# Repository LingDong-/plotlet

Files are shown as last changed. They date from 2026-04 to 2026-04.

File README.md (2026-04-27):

# plotlet

A $20 pen-plotter design that you can (almost) entirely 3D-print yourself. Optionally wireless: Bluetooth-operated and battery powered with upgrades.

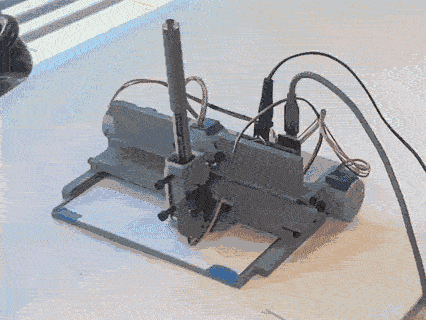
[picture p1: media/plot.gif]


While not as fast or accurate as a full-blown plotter with metal parts and big motors, this delightful little machine is surprisingly capable for a tiny fraction of the cost. The default work area is the size of a postcard (6''x4''), while a simple modification allows it to cover 6''x ∞.

## Gallery

Below are some plots made with the plotter. Click on the image to enlarge.

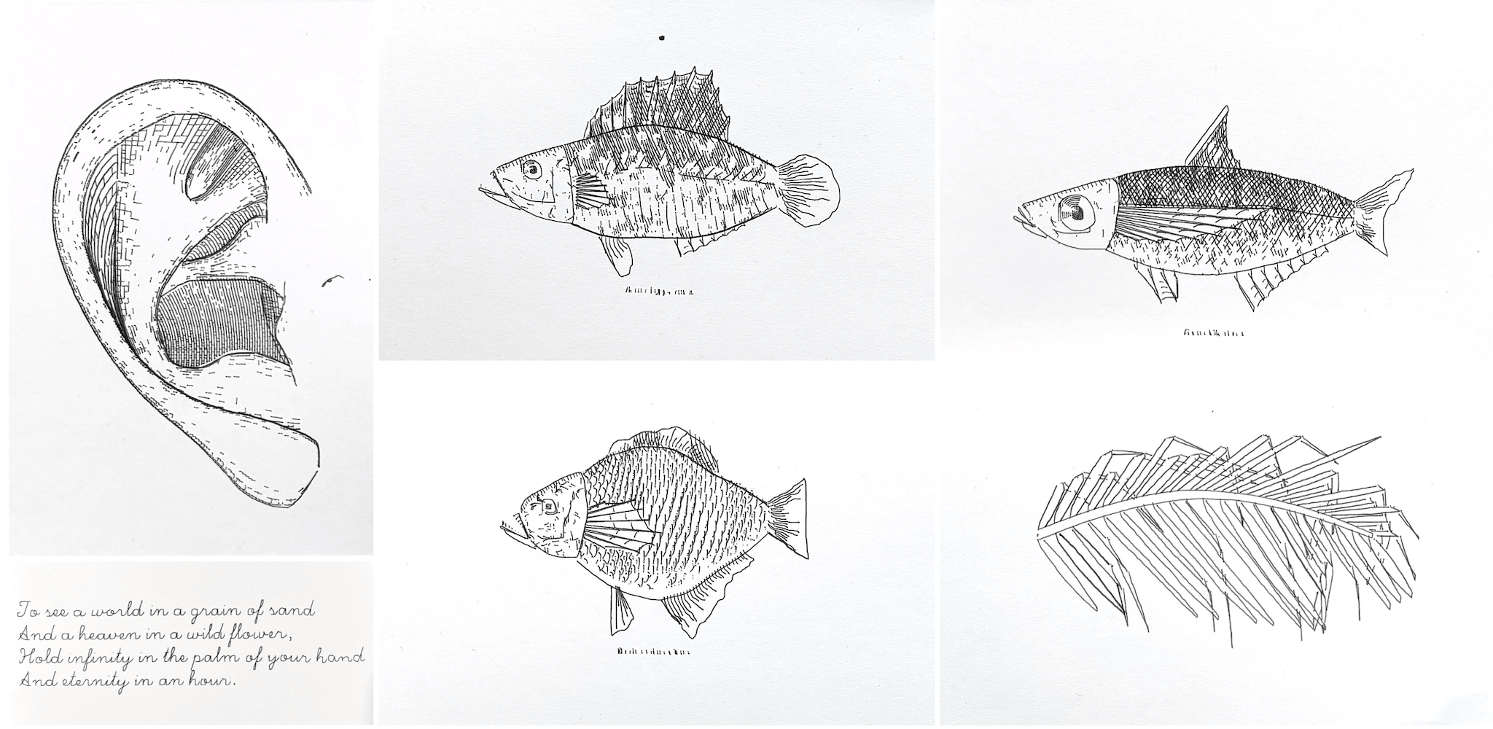
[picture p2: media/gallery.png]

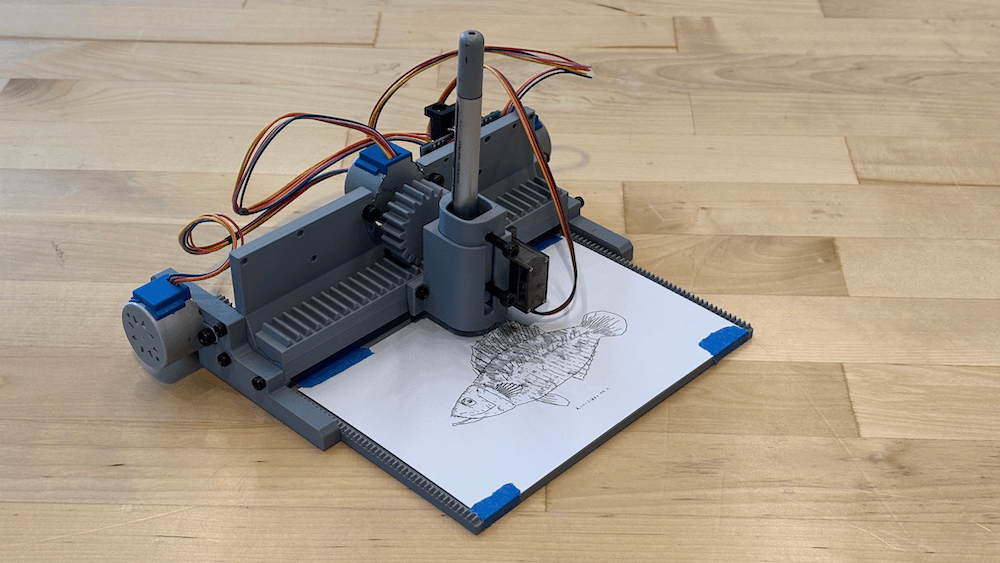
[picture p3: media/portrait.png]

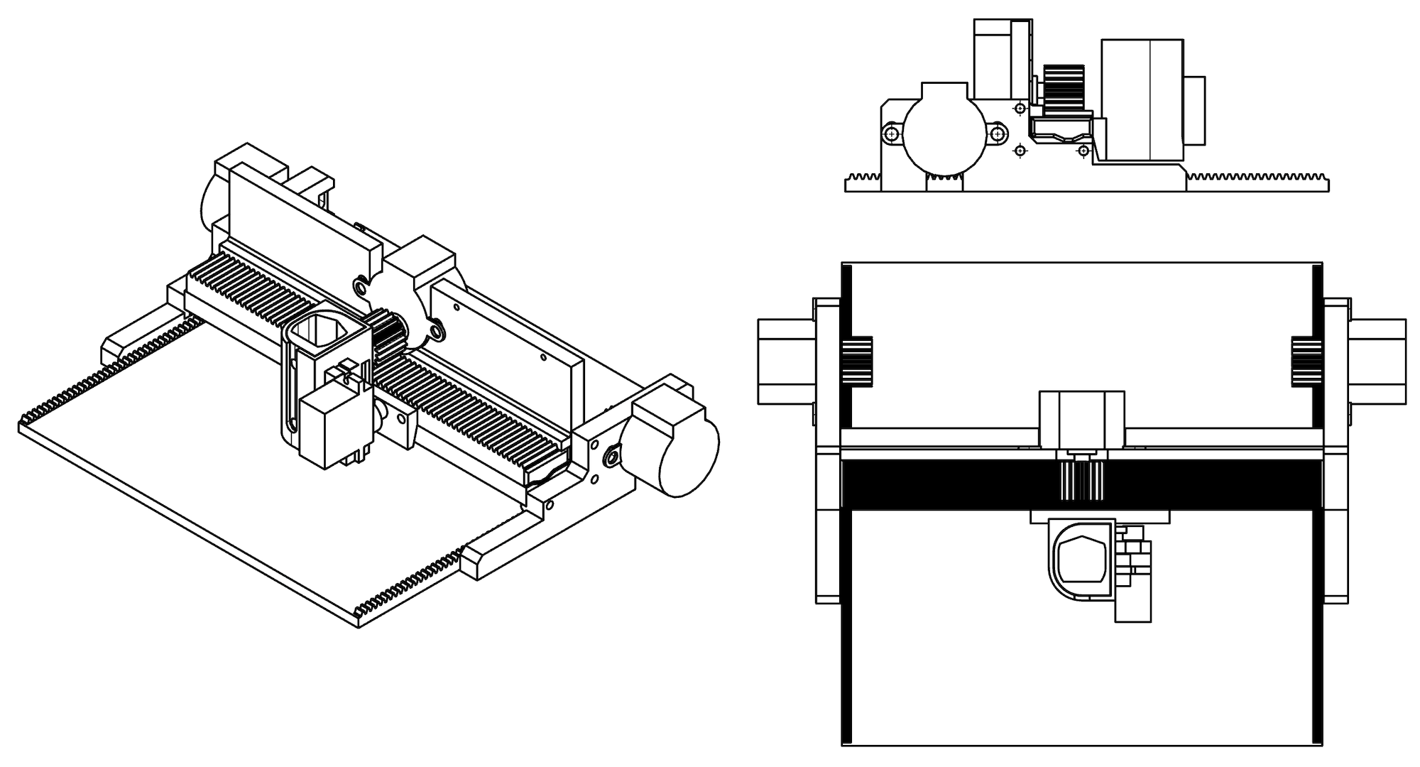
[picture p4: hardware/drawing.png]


## BOM

| Part | Qty | Unit Cost | Cost* | Link |
|---|-----|---|---|---|
| Stepper 28BYJ48 12V w/ driver |  3  | $2.4 | $7.2 | [Amazon](https://www.amazon.com/dp/B0CZNGF43R) |
| Servo SG90 |  1  | $1.8 | $1.8 | [Amazon](https://www.amazon.com/dp/B0D6FR6WYV) |
| M2/M3/M4 bolts & nuts* | 21  | $0.01 | $0.23 | [Amazon](https://www.amazon.com/dp/B0FJFVG31G) |
| 3D printer filament | 150g| $14/kg | $2.1 | [Amazon](https://www.amazon.com/dp/B07PGY2JP1) |
| 12V 1A Power Supply |  1  | $4 | $4 | [Amazon](https://www.amazon.com/dp/B0FWC9LRYZ) |
| Arduino + wires* |  1  | $5 | $5 | [Amazon](https://www.amazon.com/dp/B0DFGQW2ZY) |
| **Total** | | |**$20.3** | |

* Cost is in US dollars.
* M2x12mm x1, M3x12mm x8, M4x12mm x8, M4 nuts x6. Additional screws required if electronics are to be fastened to plotter body.
* Minimal setup requires an Arduino Nano knockoff (or any Arduino board) and dupont wires. Or, upgrade to the custom, more integrated PCB found in [circuit/](circuit/) folder. More info and wiring help can be found in Wiring section below.

## 3D Printing

All parts can be 3D printed reliably with no support structure.

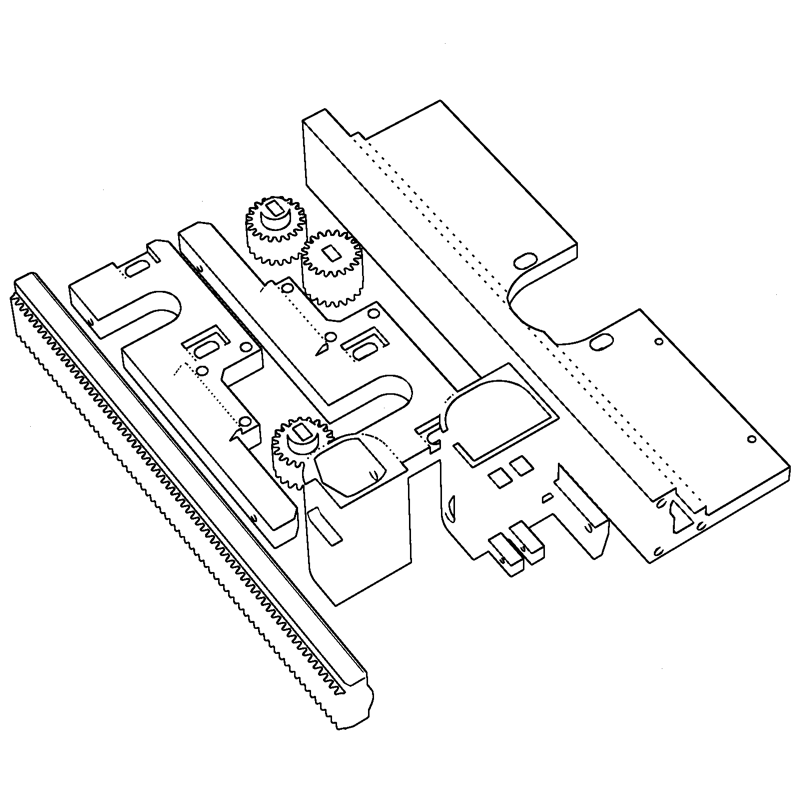
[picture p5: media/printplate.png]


1. Download [plotter-standard.step](hardware/plotter-standard.step) from [hardware/](hardware/) folder.
2. In slicer, break into components, and delete non-3D-printed parts such as motors.
3. Orient each component such that the cross section with the most prominent feature is parrallel to the build plate (see above image for a recommanded arrangement).
4. In theory, all parts can be fit into a single 256x256mm plate (~4 hours on a Bambu printer), though it is recommanded to print the flatbed part separately.
5. The usual 0.2mm layer height, 2 wall loops, 15% infill, or simply sticking to slicer defaults should suffice.

## Assembly

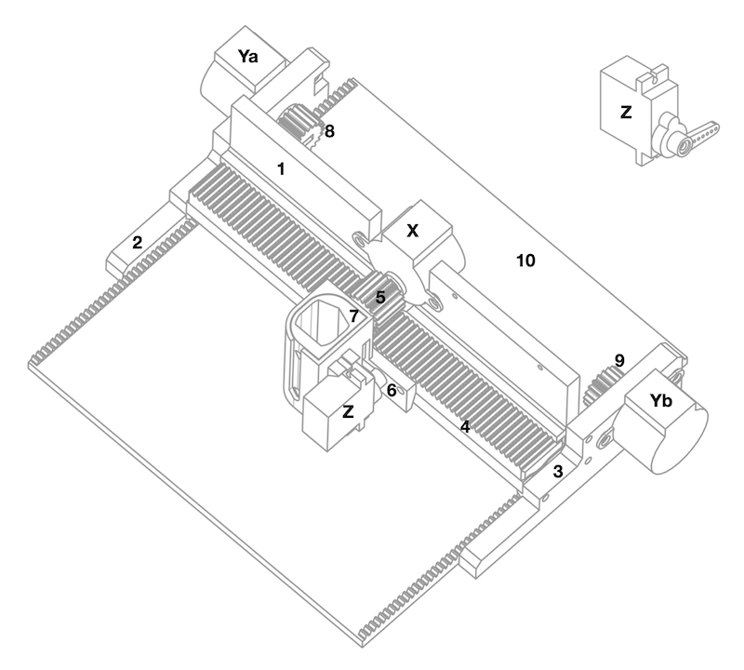
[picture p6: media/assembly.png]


Before assembly, ensure servo motor Z is in the 90-degree (central) position, and attach single-armed servo horn as shown. You can turn/test a servo with [firmware/servo_calib_arduino](firmware/servo_calib_arduino).

1. Fasten motor Z to part 6 with 1x M2 bolts;
2. Fasten part 6 to part 4 with 2x M3 bolts;
3. Slide part 4 into part 1;
4. Attach part 5 to motor X;
5. Fasten motor X to part 1 with 2x M4 bolts and nuts, ensure gears mesh smoothly
6. Loosely attach motor Ya to part 2, Yb to 3, do not tighten;
7. Fasten part 2 and 3 to 1 with 3x M2 bolts each;
8. Place part 10, attach part 8 to Ya, 9 to Yb;
9. Tighten Ya to 2, Yb to 3, ensure gears mesh smoothly;
10. Fasten pen to part 7 with 2x M4 bolts, slide part 7 into part 6.

### Tips

- Well-assembled machines can achieve higher plotting accuracy.
- Depending on the type of pen and paper used, you can attach a weight onto the pen to make the Z carriage more heavy and make bolder marks.

## Wiring & Firmware

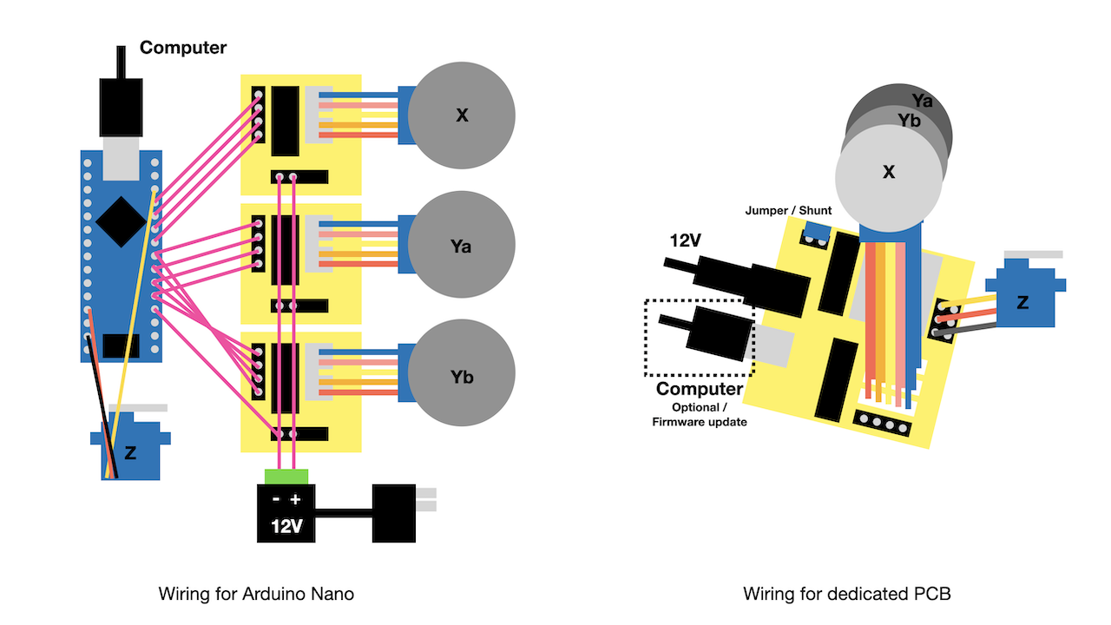
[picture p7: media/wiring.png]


### Option 1: Quick and Dirty

The easiest way to get the circuit up and running, is to wire an Arduino Nano (or knockoff thereof) as shown in the image above. The ULN2003-based drivers typically come with stepper purchase.

Then upload [firmware/plotter_nano_arduino](firmware/plotter_nano_arduino) using Arduino IDE.

Other Arduino-compatible boards should also work, but you might need to modify the pin numbers.

### Option 2: Order PCB

A custom, dedicated PCB design is also included in this repo if you'd like a nicer solution. It is more compact, less cable management, and enables plotting via Bluetooth.

The EasyEDA project can be found at [circuit/plotter-esp.epro](circuit/plotter-esp.epro). The schematic is also available as an image at [circuit/plotter-esp-sch.png](circuit/plotter-esp-sch.png), and gerber files, the BOM, and pick and place file are also available in the same folder.

All the components are easily hand-solderable. The ULN2003 chips can be detached from the driver boards that come with stepper purchase, and soldered or socketed to this board. After assembly, wire as shown in the above image.

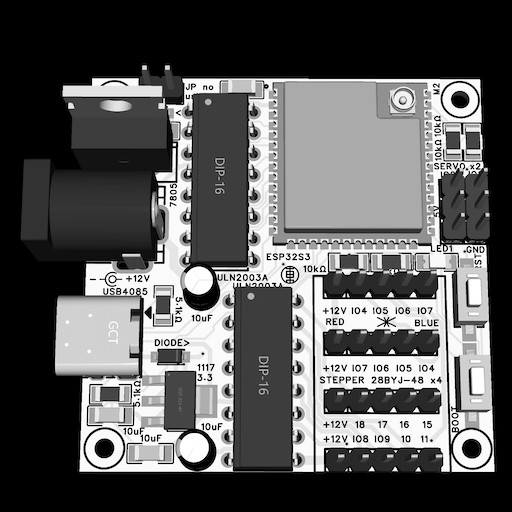
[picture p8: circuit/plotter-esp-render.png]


To additionally power the microcontroller and servo motor from the 12V power supply (thus eliminating the need for the USB-C cable when communicating via Bluetooth), short the jumper labelled "JP no usb" with a shunt or wire. If you do so, attach a heatsink to the 7805 for good measure.

Then upload [firmware/plotter_esp_arduino](firmware/plotter_esp_arduino) using Arduino IDE. Ensure USB CDC, USB JTAG are enabled in the Tools menu.

### Other Options

You can also use an ESP32-S3 dev board with [firmware/plotter_esp_arduino](firmware/plotter_esp_arduino) firmware and wire / edit pin numbers accordingly.

You can also make a proto/perf/strip board following either design, as a middle ground, which was how I made the first version of the circuit.

### A Note on Steppers

This project uses the 12V version of 28BYJ48 instead of the 5V version, since it has higher torque per [datasheet](https://www.aksotronik.com.pl/media/products_files/009433.pdf). However, the 5V version can probably be made to work too. In this case, use a 5V power supply, and for the custom PCB, short the input and output pins of the 7805.

## Protocol

The plotter understands a simple GCODE-like language inspired by SVG paths, sent via serial (baud rate 115200). Currently there are only two commands. For **relative**, **l**inear move on the XY-plane (unit in steps, case-sensitive):

```
l100,200\n
```

For **absolute** positioning of the **Z**-axis (unit in degrees):

```
Z150\n
```

There're approximately 1600 steps along the X-axis (800 in either direction), and 1000 steps along the Y-axis (if using the default 6''x4'' bed). For Z-axis, 90deg is the pen-down position, while 150deg is the pen-up position. e.g. to draw a square:

```
Z90
l100,0
l0,100
l-100,0
l0,-100
Z150
```

Numbers must be integers. Commands are sent one at a time to the firmware, terminated by "\n". Only upon receiving the string "OK\n" back, may the software send the next command.

The easiest way to test is by opening Arduino IDE's serial monitor, set baud to 115200, line ending to newline and type the commands to send.

The machine itself does not have a notion of "home", and will start moving from whatever position it is currently at. However, it is recommanded that you set up by moving the gear rack of X axis squarely to the center with no part protruding out of either side, and align the pen with the upper edge of the workpiece. In this case, the coordinate of the four corners will be (-800,0), (800,0), (-800,1000) and (800,1000).

For bluetooth communication, the commands follow the same format, but are written to a BLE characteristic, and the "\n" may be omitted. Upon completion, the firmware overwrites the characteristic with "OK".

The syntax is chosen for simplicity and direct mapping to the hardware (which is simple itself). If you somehow prefer real GCODE, you can try to flash [grbl firmware](https://github.com/grbl/grbl) onto the board (and share your results).

## Software

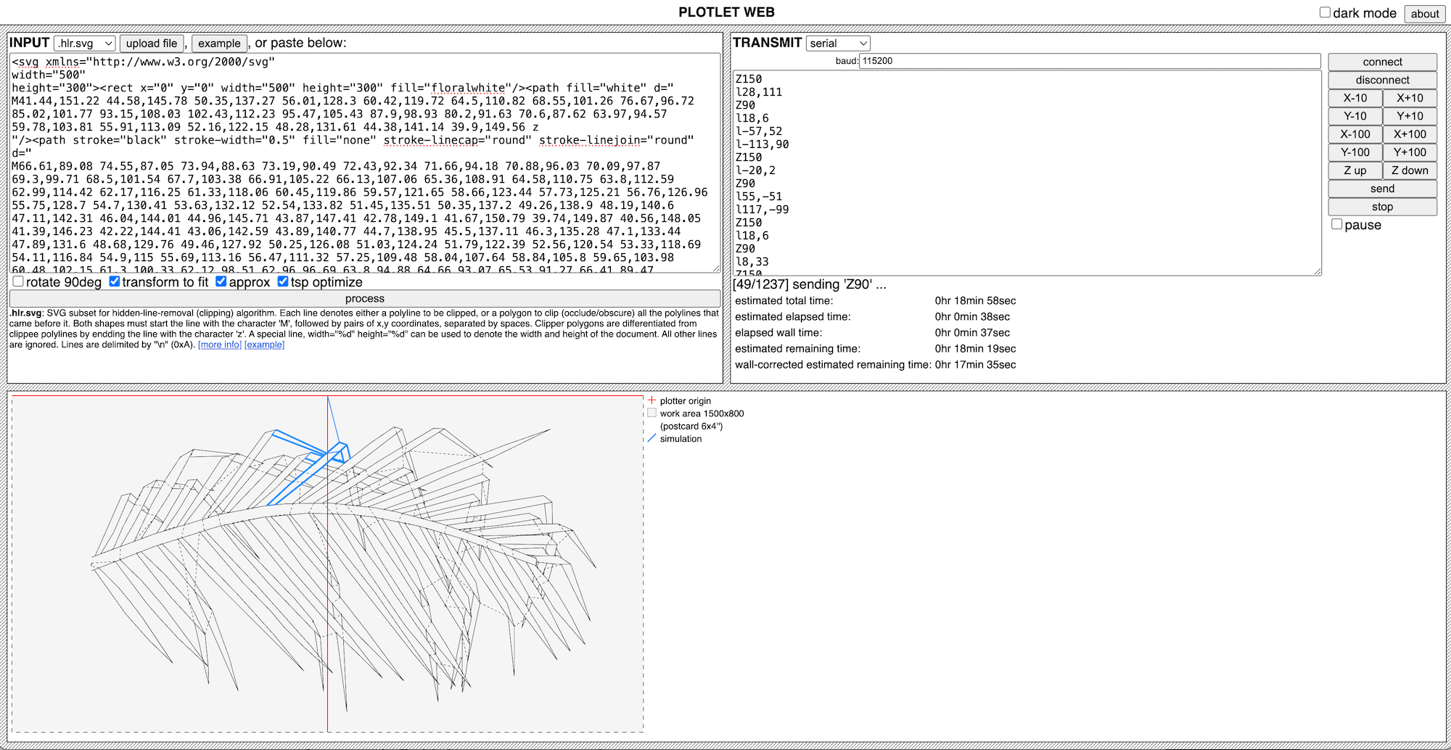
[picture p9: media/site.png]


The easiest way to send jobs to the plotter is via the web interface located in [software/](software/). To launch, start a local server in the folder, e.g.

```
cd software
python3 -m http.server
```

Then open the page in **Chrome** browser, as it uses Web Serial and Web Bluetoth, which are not supported by some browsers such as Safari. You can check compatibility [here](https://developer.mozilla.org/en-US/docs/Web/API/Web_Bluetooth_API#browser_compatibility), [here](https://developer.mozilla.org/en-US/docs/Web/API/Web_Serial_API#browser_compatibility) and [here](https://caniuse.com/).

### Input Format

There are a few options from the drop-down menu:

- The most convenient one is probably SVG. SVG is a common format for vector graphics. You can find some [samples from w3.org](https://dev.w3.org/SVG/tools/svgweb/samples/svg-files). If you used p5.js to generate the drawing, you can use [p5.plotSvg](https://github.com/golanlevin/p5.plotSvg) to make an SVG.

- The tool also support **.hlr.svg**, a custom subset of SVG for pre-processing with a clipping / [hidden line removal](https://en.wikipedia.org/wiki/Hidden-line_removal) algorithm. The basic idea is, on a screen, if you draw an opaque shape on top of another, the one underneath will be eclipsed (a.k.a. [painter's algorithm](https://en.wikipedia.org/wiki/Painter%27s_algorithm)). However, plotters typically does not have a means of erasing what was already drawn. This format allows you to specify shapes that clip others v.s. shapes that are clipped by others, so the pre-processing algorithm can compile a list of clipped shapes than can be plotted directly. The algorithm and format are initially developed for [this drawing with 0.3 million shapes](https://github.com/LingDong-/galiano-drawing). Format spec and more info in the in-app tooltips.

- Of course, plain old **polylines** are also supported, which takes the form of a JSON/JavaScript array: `[[[x0,y0],[x1,y1],...],...]`. This option is perhaps the most convenient if you're generating the drawing algorithmically and know what you're doing, since it doesn't involve a round trip to another format.

- Finally, with the **text** option, you can type some text and have them plotted with [single-stroke font](https://paulbourke.net/dataformats/hershey/). This should mostly be for testing, and if you need any fancy typographic features, you should generate your own and encode in any of the other formats above.

### Post-Processing

- **rotate 90degs**: switch from portrait to landscape and vice versa.
- **transform to fit**: fit the drawing to the workarea and center it. A lazy option, and if you care about margins etc. you should generate the drawing with the correct dimensions (1px = 1step) yourself.
- **approx**: simplify the polylines before plotting, removing inconspicous details. (Uses [Doug-Peucker](https://en.wikipedia.org/wiki/Ramer%E2%80%93Douglas%E2%80%93Peucker_algorithm)).
- **tsp optimize**: minimize the distance of jumps between polylines by reordering them and/or flipping them. Approximate soltion to a variant of the [travelling salesperson's problem](https://en.wikipedia.org/wiki/Travelling_salesman_problem). Saves plotting time.

### Genrating Toolpath

Next, simply click the big "process" button. You'll see the commands generated in the big text box of the "Transmit" window. Alternatively, you can also paste raw commands into that text box directly, thereby skipping all the previous steps, for testing or fine control.

Verify that the drawing is parsed and positioned as expected in the preview window on the lower half of the page.

### Connecting

To plot, first you need to connect to the plotter. You can either use Bluetooth (BLE) if your circuit setup supports it (see previous sections), or the wired, Serial (USB) option, chosen from the drop-down menu. (Again, not all browsers support Web Bluetooth and Web Serial, and Chrome is recommanded). The default parameters should be fine as long as you didn't modify the firmware. Then click "connect". The browser should prompt you which device to pair with / connect to; select the most likely option.

You can test your connection and / or home your plotter by clicking the "X-10", "Y+100", "Z down" etc. buttons, which move the plotter's axes directly by sending corresponding commands.

### Plotting

Finally, click the "send" button to transmit the commands generated from your drawing. You can see a real-time simulation of the plotting process in the preview window, as well as status updates in the transmit window. Your plotter should be busy plotting the stuff, and you can drink some tea and wait.

If you encounter any problems, check the browser's [developer console](https://developer.chrome.com/docs/devtools/open). If you think it's a bug, let me know in the Issues section.

### Programmatic Control / Libraries

- example controlling from p5.js available at [https://editor.p5js.org/lingdong/sketches/d-jyu31fy](https://editor.p5js.org/lingdong/sketches/d-jyu31fy)

## Upgrades

### More Stable Z Axis for Pilot G2 Pens

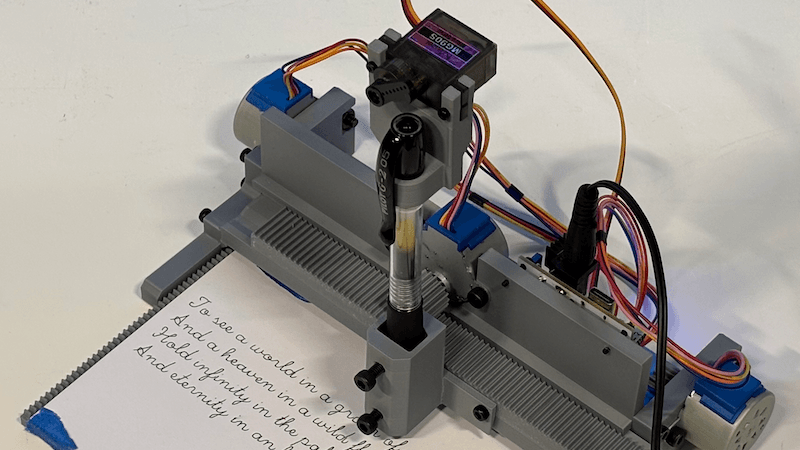
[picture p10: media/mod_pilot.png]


- The original Z axis causes some small give on the XY plane due to gap between 3D printed "carriage" and "rail". 
- Clicky pen (e.g. [Pilot G2](https://www.amazon.com/dp/B00006JNJ8)) retraction mechanism has much better manufacturing tolerance than 3D printed parts, and can be abused in place of Z axis.
- Download [hardware/plotter-alt-z-pilotg2.step](hardware/plotter-alt-z-pilotg2.step) and [hardware/plotter-alt-z-none.step](hardware/plotter-alt-z-none.step) and 3D print both.
- Before assembly, remove the spring in the G2 by unscrewing the pen body. Otherwise the servo can have trouble compressing it repeatedly over time. (It turns out, when the tip of G2 is lightly dragged over a surface, it does not leave a mark, pressure is required to do so, therefore, the spring is not needed)
- First assemble without fastening tightly. Make the pen tip protrude as far as possible, and let it press firmly on the paper. Now fasten tightly.
- The firmware can remain unchanged. Try plotting, and adjust assembly if pen is too low or too high.

### Infinite Y Axis with Timing Belts

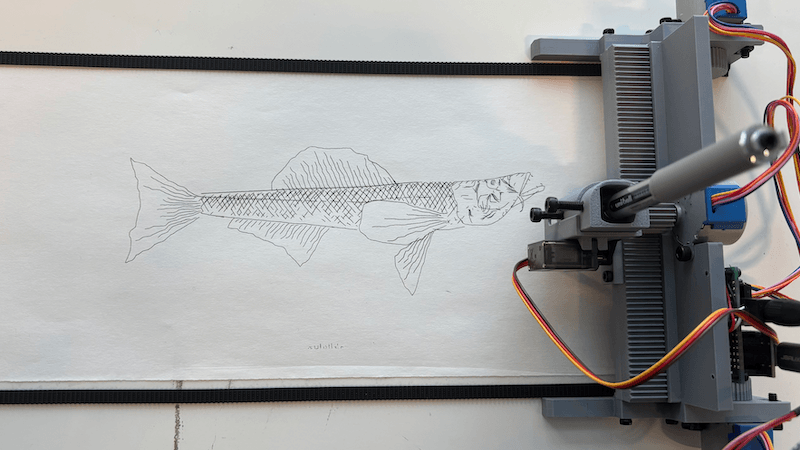
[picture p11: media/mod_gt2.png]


- Accquire [GT2-2M timing belts](https://www.amazon.com/dp/B097T3Y6WW).
- Download [hardware/plotter-alt-y-gt2.step](hardware/plotter-alt-y-gt2.step) and 3D print **2 copies**.
- Replace original Y axis gears with these, and loosen the bolts on Y axis stepper motors.
- Use double-sided tape (or some other adhesive) to install a pair of timing belts on a flat surface such as a tabletop.
- Sit the plotter on top of the timing belts, and tighten the bolts on Y axis steppers.
- The new gears are 1.5x larger, therefore Y axis will be 1.5x faster/coarser, and all drawings sent need to be vertically scaled by 66% to keep proportions.

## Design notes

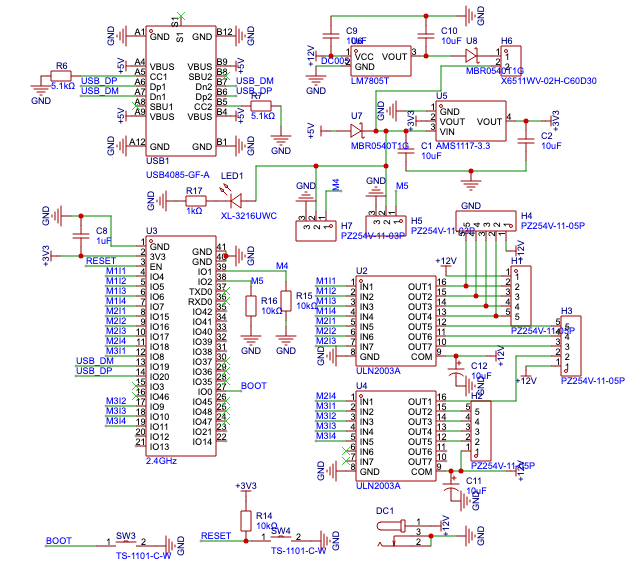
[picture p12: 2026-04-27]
circuit/plotter-esp-sch.png

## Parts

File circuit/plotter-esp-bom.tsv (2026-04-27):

No. | Quantity | Comment | Designator | Footprint | Value | Manufacturer Part | Manufacturer | Supplier Part | Supplier
1 | 4 | 10uF | C1,C2,C9,C10 | C1206 | 10uF | CL31A106KAHNNNE | SAMSUNG(三星) | C9807 | LCSC
2 | 1 | 1uF | C8 | C1206 | 1uF | CL31B105KBHNNNE | SAMSUNG(三星) | C1848 | LCSC
3 | 2 | 10uF | C11,C12 | CAP-TH_BD4.0-P1.50-D0.8-FD | 10uF | KF106M025C05RR0VH2FP0 | Chengx(承兴) | C43846 | LCSC
4 | 1 | DC005 | DC1 | DC-IN-TH_DC005 |  | DC005 | SHOU HAN(首韩) | C431533 | LCSC
5 | 4 | PZ254V-11-05P | H1,H2,H3,H4 | HDR-TH_5P-P2.54-V-M |  | PZ254V-11-05P | XFCN(兴飞) | C492404 | LCSC
6 | 2 | PZ254V-11-03P | H5,H7 | HDR-TH_3P-P2.54-V-M_PZ254V-11-03P |  | PZ254V-11-03P | XFCN(兴飞) | C2937625 | LCSC
7 | 1 | X6511WV-02H-C60D30 | H6 | HDR-TH_2P-P2.54-V-M |  | X6511WV-02H-C60D30 | XKB Connection(中国星坤) | C706874 | LCSC
8 | 1 | XL-3216UWC | LED1 | LED1206-R-RD_WHITE |  | XL-3216UWC | XINGLIGHT(成兴光) | C965828 | LCSC
9 | 2 | 5.1kΩ | R6,R7 | R1206 | 5.1kΩ | FRC1206J512 TS | FOJAN(富捷) | C2907509 | LCSC
10 | 3 | 10kΩ | R14,R15,R16 | R1206 | 10kΩ | FRC1206J103 TS | FOJAN(富捷) | C2907423 | LCSC
11 | 1 | 1kΩ | R17 | R1206 | 1kΩ | FRC1206J102 TS | FOJAN(富捷) | C2907440 | LCSC
12 | 2 | TS-1101-C-W | SW3,SW4 | SW-SMD_L6.0-W3.3-LS8.0 |  | TS-1101-C-W | XKB Connectivity(中国星坤) | C318938 | LCSC
13 | 2 | ULN2003A | U2,U4 | DIP-16_L20.0-W6.4-P2.54-LS7.6-BL |  | ULN2003A | ST(意法半导体) | C93000 | LCSC
14 | 1 | 2.4GHz | U3 | WIRELM-SMD_ESP32-S3-WROOM-1U | 2.4GHz | ESP32-S3-WROOM-1U | ESPRESSIF(乐鑫) | C3013943 | LCSC
15 | 1 | AMS1117-3.3 | U5 | SOT-223-3_L6.5-W3.4-P2.30-LS7.0-BR |  | AMS1117-3.3 | AMS | C6186 | LCSC
16 | 1 | LM7805T | U6 | TO-220-3_L10.1-W4.7-P2.54-L |  | LM7805T | HGSEMI(华冠) | C7432180 | LCSC
17 | 2 | MBR0540T1G | U7,U8 | SOD-123_L2.8-W1.8-LS3.7-RD |  | MBR0540T1G | HXY MOSFET(华轩阳电子) | C20611940 | LCSC
18 | 1 | USB4085-GF-A | USB1 | USC-C-SMD_USB4085-GF-A |  | USB4085-GF-A | GCT | C7095263 | LCSC

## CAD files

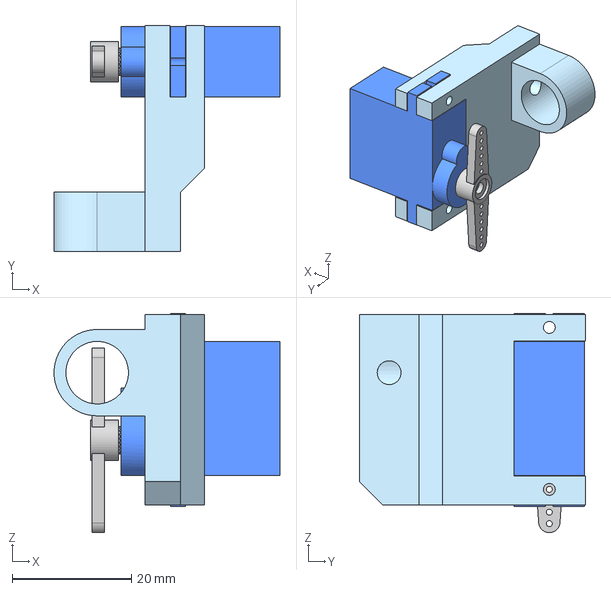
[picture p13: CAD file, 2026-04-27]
hardware/plotter-alt-z-pilotg2.step
38.0 x 38.0 x 36.8 mm

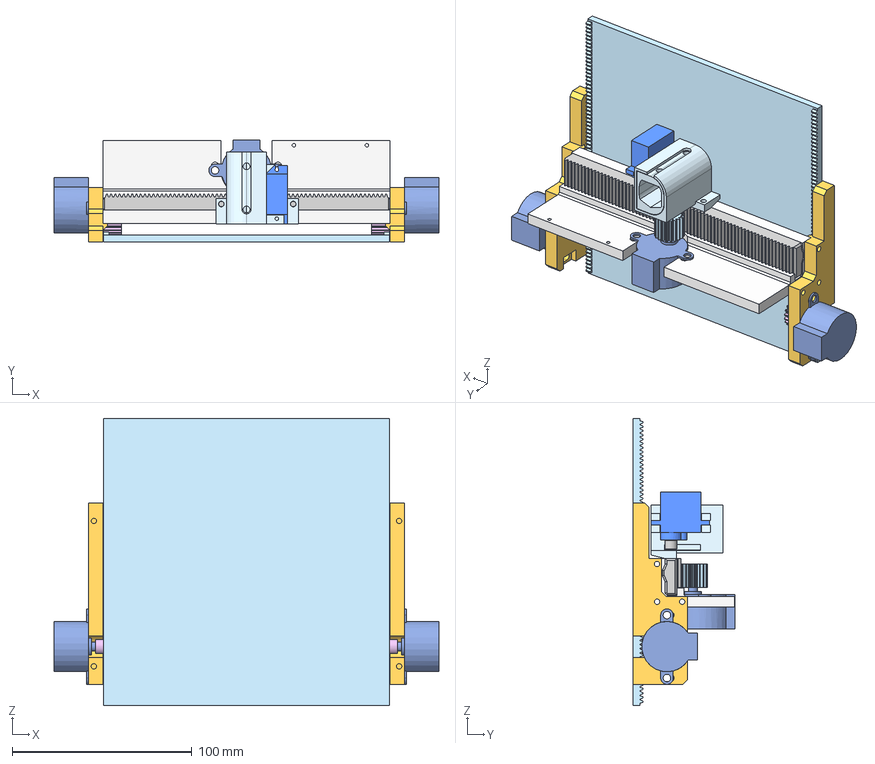
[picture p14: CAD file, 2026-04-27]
hardware/plotter-standard.step
214.4 x 57.0 x 160.0 mm

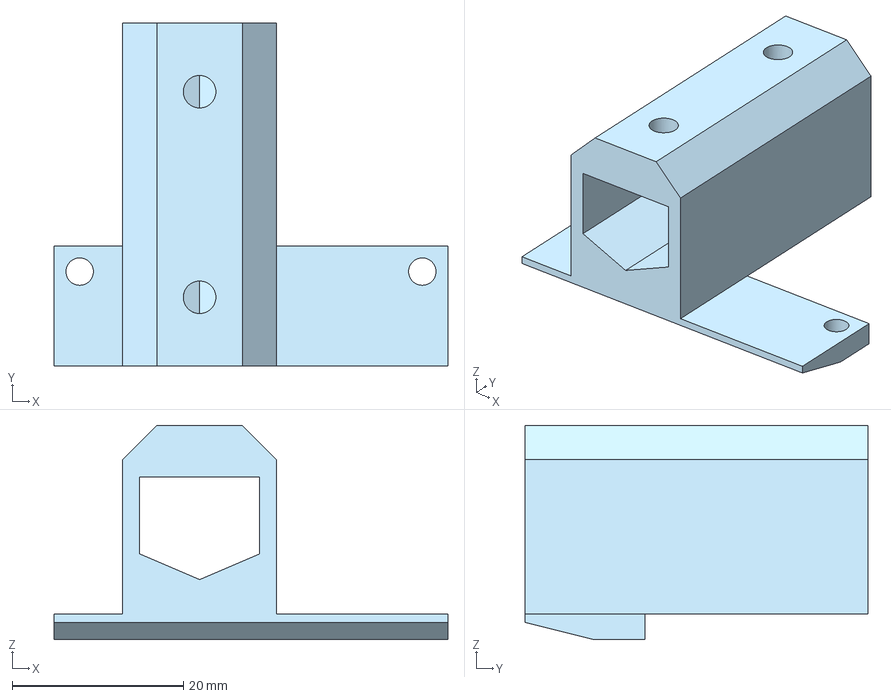
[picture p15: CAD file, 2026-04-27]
hardware/plotter-alt-z-none.step
46.0 x 40.0 x 25.0 mm

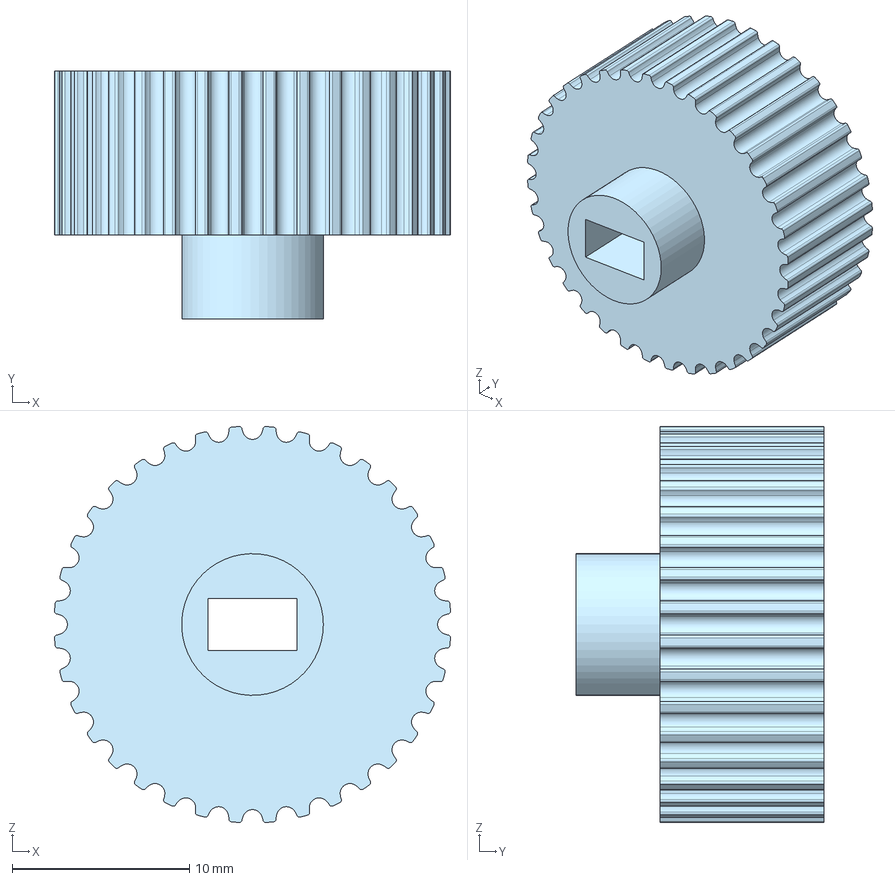
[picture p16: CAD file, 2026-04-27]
hardware/plotter-alt-y-gt2.step
22.4 x 14.0 x 22.4 mm

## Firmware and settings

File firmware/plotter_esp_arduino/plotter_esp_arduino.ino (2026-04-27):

#include <BLEDevice.h>
#include <BLEUtils.h>
#include <BLEServer.h>

#define SERVICE_UUID "5817e2d6-642e-4523-8098-259279a002f2"
#define CHARACTERISTIC_UUID "5ed7832a-308b-427b-b99c-77a56e362349"


static const int SERVO_FREQ       = 50;
static const int SERVO_RESOLUTION = 14;
static const int SERVO_MIN_US     = 544;
static const int SERVO_MAX_US     = 2400;
static const int PERIOD_US        = 20000;


int YIN1 = 4;
int YIN2 = 5;
int YIN3 = 6;
int YIN4 = 7;

int XIN1 = 15;
int XIN2 = 16;
int XIN3 = 17;
int XIN4 = 18;

int SR1 = 2;

int step_delay = 4;

int seq[4][4] = {
  {1,0,0,0},
  {0,1,0,0},
  {0,0,1,0},
  {0,0,0,1}
};

static uint32_t us2ticks(int us) {
  return (uint32_t)((uint64_t)us * ((1 << SERVO_RESOLUTION) - 1) / PERIOD_US);
}

void feed(int dir){
  for(int i = 0; i < sizeof(seq)/sizeof(seq[0]); i++){
    int j = (dir<0) ? (3-i) : i;
    digitalWrite(YIN1, seq[j][0]);
    digitalWrite(YIN2, seq[j][1]);
    digitalWrite(YIN3, seq[j][2]);
    digitalWrite(YIN4, seq[j][3]);
    delay(step_delay);
  }
}

void head(int dir){
  for(int i = 0; i < sizeof(seq)/sizeof(seq[0]); i++){
    int j = (dir>0) ? (3-i) : i;
    digitalWrite(XIN1, seq[j][0]);
    digitalWrite(XIN2, seq[j][1]);
    digitalWrite(XIN3, seq[j][2]);
    digitalWrite(XIN4, seq[j][3]);
    delay(step_delay);
  }
}

void moveby(int x1, int y1){
  int x0 = 0;
  int y0 = 0;
  int dx = abs(x1 - x0);
  int sx = (x0 < x1) ? 1 : -1;
  int dy = -abs(y1 - y0);
  int sy = (y0 < y1) ? 1 : -1;
  int error = dx + dy;
  while (true){
    int e2 = 2 * error;
    if (e2 >= dy){
      if (x0 == x1) break;
      error += dy;
      x0 += sx;
      head(sx);
    }
    if (e2 <= dx){
      if (y0 == y1) break;
      error += dx;
      y0 += sy;
      feed(sy);
    }
  }
}

void sr_write(int pin, int ang){
  int n = map(ang, 0, 180, SERVO_MIN_US, SERVO_MAX_US);
  for (int i = 0; i < 25; i++){
    digitalWrite(pin, HIGH);
    delayMicroseconds(n);
    digitalWrite(pin, LOW);
    delayMicroseconds(PERIOD_US-n);
  }

  // ledcWrite(pin, us2ticks(n));
  // delay(500);
}

void sr_attach(int pin){
  pinMode(SR1,  OUTPUT);
  // ledcSetClockSource(LEDC_USE_APB_CLK);
  // ledcAttach(pin, SERVO_FREQ, SERVO_RESOLUTION);
}

char* parse_run(const char* buffer){
  if (buffer[0] == 'l'){
    char *comma = strchr(buffer, ',');
    if (comma != NULL) {
      *comma = '\0';             
      int x = atoi(buffer + 1);    
      int y = atoi(comma + 1);
      moveby(x,y);
      return "OK";
    }
  }else if (buffer[0] == 'Z'){
    int z = atoi(buffer+1);
    sr_write(SR1,z);
    return "OK";
  }
}


class BleCb: public BLECharacteristicCallbacks {
  void onWrite(BLECharacteristic *pCharacteristic){
    String value = pCharacteristic->getValue();
    if (value.length() > 0){
      pCharacteristic->setValue(parse_run(value.c_str()));
    }
  }
};

class BleSv : public BLEServerCallbacks {
  void onDisconnect(BLEServer* pServer){
    pServer->getAdvertising()->start();
  }
};

void ble_init(){
  BLEDevice::init("BLEPLOTTER");
  BLEServer *pServer = BLEDevice::createServer();
  pServer->setCallbacks(new BleSv());
  BLEService *pService = pServer->createService(SERVICE_UUID);
  BLECharacteristic * pCharacteristic = pService->createCharacteristic(
    CHARACTERISTIC_UUID, BLECharacteristic::PROPERTY_READ | BLECharacteristic::PROPERTY_WRITE
  );
  pCharacteristic->setCallbacks(new BleCb());
  pService->start();  
  BLEAdvertising * pAdvertising = pServer->getAdvertising();
  pAdvertising->start();
}


const int BUFFER_SIZE = 64;
char buffer[BUFFER_SIZE];
int bufidx = 0;

void setup() {
  Serial.begin(115200);
  pinMode(XIN1, OUTPUT);
  pinMode(XIN2, OUTPUT);
  pinMode(XIN3, OUTPUT);
  pinMode(XIN4, OUTPUT);
  pinMode(YIN1, OUTPUT);
  pinMode(YIN2, OUTPUT);
  pinMode(YIN3, OUTPUT);
  pinMode(YIN4, OUTPUT);
  
  sr_attach(SR1);
  sr_write(SR1,150);
  ble_init();
}


void loop() {
  while (Serial.available()) {
    char c = Serial.read();
    if (c == '\n') {
      buffer[bufidx] = '\0';
      Serial.print(parse_run(buffer));
      Serial.print("\n");
      bufidx = 0;
    }
    else {
      if (bufidx < BUFFER_SIZE - 1) {
        buffer[bufidx++] = c;
      } else {
        bufidx = 0;
      }
    }
  }
}
